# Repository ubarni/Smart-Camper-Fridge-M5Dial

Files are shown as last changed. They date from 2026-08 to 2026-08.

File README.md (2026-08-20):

# Smart Camper Fridge Controller (M5Dial)

An advanced, fully integrated open-source controller for 12V/24V camper refrigerators using SECOP (Danfoss) compressors, powered by an [**M5Stack Dial 1.1**](https://docs.m5stack.com/en/core/M5Dial) running **ESPHome** with **Home Assistant Integration**.

Tested with [**WAECO Coolmatic MDC-090K**](https://github.com/ubarni/Smart-Camper-Fridge-M5Dial/blob/c926922314870ae8d956f22f25ac7502f4ca9708/manual-coolmatic-mdc090k.pdf) and [**SECOP 101N0650 Controller**](https://github.com/ubarni/Smart-Camper-Fridge-M5Dial/blob/c926922314870ae8d956f22f25ac7502f4ca9708/secop_bd35f_bd50f_bd35k_electronic_unit_101n0212_101n0340_101n0650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)

This project provides a modern, touch-enabled smart UI for your fridge, replacing analog thermostats with precise digital temperature management, dynamic compressor speed control, Freezer Guard mode and built-in battery protection.

https://github.com/user-attachments/assets/8034e03e-43d9-4a4a-a77b-4d3339af659d

## Screenshot Home Assistant
[**Smart Fridge (View)**](https://github.com/ubarni/Smart-Camper-Fridge-M5Dial/blob/3c6792e76c0abe57d38a256c658d0e316bda5d45/smart_fridge_view.yaml)
Install via HACS: Template Climate (Integration), Bubble Card (Dashboard), Button Card (Dashboard), Lovelace Mini Graph Card (Dashboard), Card Mod 4 (Dashboard)
Needs: [**climate_template.yaml**](https://github.com/ubarni/Smart-Camper-Fridge-M5Dial/blob/3c6792e76c0abe57d38a256c658d0e316bda5d45/climate_template.yaml)
Bildschirmfoto 2026-08-06 um 20 25 00

## ✨ Features

* **Modern Touch UI & Rotary Encoder:** Intuitive control over temperature and compressor speeds using the M5Dial's rotating bezel and round touch screen.
* **Intelligent Compressor Control:** Variable PWM speed control allows you to run the compressor in `Night` (Quiet/Slow), `Normal`, or `Power` (Fast cooling) modes.
* **Dual-Zone "Freezer Guard" Mode:** Single-compressor RV refrigerators share a single cooling circuit between the main compartment and the freezer. When the Freezer Guard Mode is ON the compressor logic reacts on fridge AND freezer target temperatures. 
* **Locktime:** Prevents the compressor from starting within a preset time. This extends the compressors lifetime.
* **Low Voltage Disconnect (LVD):** Monitors battery voltage and safely shuts down the fridge before your camper's battery is depleted (Configurable via Home Assistant).
* **Failsafe Mechanisms:** Prevents infinite compressor loops if a temperature sensor fails or gets disconnected.
* **SECOP Error Decoding:** Directly reads and decodes the diagnostic pulses from the SECOP controller (e.g., "E3: Motor failure") and displays the exact cause on the screen.
* **Software Power Meter:** Accurately estimates current power consumption (Watts) and integrates it into total Energy (Wh) used.
* **100% Home Assistant Integration:** All presets, parameters, and logs are seamlessly synced with Home Assistant.

## 🛠️ Hardware Requirements

* **M5Stack M5Dial 1.1**
  * 1x [**M5Stack Dial 1.1**](https://shop.m5stack.com/products/m5stack-dial-v1-1) (ESP32-S3 with integrated touch display and rotary encoder) https://shop.m5stack.com/products/m5stack-dial-v1-1
* **DS18B20 Temperature Sensors**
  * 3x DS18B20 temperature sensors supported for Fridge, Freezer, and Compressor
  * 1x 4.7 kΩ Pull-up resistors for the DS18B20 data line
* **36V -> 3.3V analog Voltage Divider** (To safely measure the 12V/24V battery line via the M5Dial's 3.3V ADC)
  * 1x 100 kΩ + 1x 10 kΩ **1% Metal film resistor**
  * 1x 100nF Condensator
* **Optocouplers:**
  * 2x PC817 (For isolating DIAG and PWM signals)
    * **PWM Output:** M5Dial GPIO39 drives the internal LED of the first PC817. The transistor side connects directly to Secop terminals **T** and **C**.
    * **DIAG Input:** Secop terminal **D** drives the second PC817 input. The output transistor pulls **GPIO38** down to GND when active. 
  * 1x 1 kΩ (PWM)
  * 1x 220Ω (DIAG)
* **Connectors:**
  * 2x [**M5Stack Grove cable**](https://shop.m5stack.com/products/4pin-buckled-grove-cable) or JST PH 2.00mm 4 pin female cables
  * 2x [**JST PH 2.00mm 4 pin male PCB connector**] for M5Dial Grove cables
  * 2x [**JST XH 2.54mm 2 pin male PCB connector**] for M5Dial power supply PCB
  * 2x [**JST XH 2.54mm 2 pin female PCB connector**] for M5Dial power supply cable
  * 1x [**JST XH 2.54mm 4 pin male connector**] for SECOP connection PCB
  * 1x [**JST XH 2.54mm 4 pin female PCB connector**] for SECOP connection cable
  * 3x [**JST XH 2.54mm 3 pin male connector**] for DS18B20 connection PCB
  * 3x [**JST XH 2.54mm 3 pin female PCB connector**] for DS18B20 connection cable

---

## 🔌 Wiring (Grove Ports)

The code is pre-configured to utilize the easily accessible Grove ports on the back of the M5Dial:

* **Port A (Red - I2C/GPIO):**
  * `GPIO15` (Yellow Wire): PWM Output to SECOP Controller (Speed limit control).
  * `GPIO13` (White Wire): Input for SECOP Error diagnostic pulses.
* **Port B (Black - I/O/ADC):**
  * `GPIO2` (Yellow Wire): Shared OneWire Data Pin for ALL DS18B20 Temperature Sensors.
  * `GPIO1` (White Wire): ADC Input for Battery Voltage Divider.
---

## Wiring "Diagram"
> ⚠️ **KiCAD and 3D print files will be available after testing**
Smart Camper Fridge M5Stack Dial
Bildschirmfoto 2026-08-19 um 16 03 24
Bildschirmfoto 2026-08-14 um 09 46 03
Bildschirmfoto 2026-08-19 um 16 02 35

**[Click here to see the 3D model of the case](https://github.com/ubarni/Smart-Camper-Fridge-M5Dial/blob/1929dae5fefd54ca2ec57aa82e2640f9eb83e18b/Smart%20Fridge%20Geha%CC%88use.stl)**

---

## Software Installation

1. Copy the contents of `smart-camper-fridge-m5dial.yaml` into your ESPHome environment.
2. The power estimation logic (`fridge_power`) is tuned for a standard SECOP BD35F compressor pulling ~57W at minimum speed and ~72W at full throttle. You can modify these values in the YAML file based on your specific compressor and cooling agent.

3. Create a `secrets.yaml` file in the same directory (or use your existing one) containing your network and access parameters based on the following template:

```yaml
wifi_ssid: "Your_Camper_WIFI"
wifi_password: "Your_Secret_Password"
wifi_backup_ssid: "Your_Backup_Home_WIFI"
wifi_backup_password: "Your_Home_Password"
ap_password: "Fallback_Access_Point_Password"
```

3. Compile and flash the firmware to your M5Dial. If transitioning between compilation environments, performing a **"Clean Build"** prior to flashing is recommended.

---
## 🖱️ User Interface (M5Dial Operation)

The M5Dial offers a highly intuitive, tactile interface using its rotary encoder, touch screen, and integrated physical button. The UI is split into three main modes, color-coded for quick recognition: **Temperature** (Blue), **Compressor Speed** (Orange), and **Brightness** (Yellow).

### 🔄 Rotary Ring (Bezel)
Turning the physical outer ring allows you to manually adjust the target value of the currently active mode:
* **In Temperature Mode:** Adjusts the fridge target temperature (1°C to 20°C).
* **In Compressor Mode:** Adjusts the compressor speed limit (0% to 100%).
* **In Brightness Mode:** Adjusts the screen backlight intensity (10% to 100%).
* **In Freezer Guard Mode:** Adjusts the freezer target temperature (0°C to -20°C).
* *Note: Manually turning the dial will instantly switch the active preset to "Manual" (unless the exact value matches a predefined preset).*

### 👆 Touch Screen Gestures
* **Tap the Center Screen:** Cycles through the three main UI modes (Temperature -> Compressor Speed -> Brightness).
* **Tap the Bottom Area:** Toggles the bottom information bar between two pages:
  * *Page 1:* Sensor Temperatures (Fridge, Freezer, Compressor).
  * *Page 2:* Energy & Connectivity (Power Draw in Watts, Battery Voltage, WiFi Signal Strength).

### 🔘 Physical Button (Below the Screen)
Below the screen of the M5Dial is a physical push button, enabling quick preset changes without looking:
* **Single Click:** Cycles through your configured presets for the currently active mode.
  * *In Temperature Mode:* Cold -> Fresh -> Eco -> Vacation -> ...
  * *In Compressor Mode:* Night -> Normal -> Power -> ...
  * *In Brightness Mode:* 30% -> 70% -> 100% -> ...
  * *In Freezer Guard Mode:* ON -> OFF -> ...
* **Double Click:** Cycles through the three main UI modes (serves as a tactile alternative to tapping the center screen).
* **Long Press (Hold for 1s):** Main Power Switch. Turns the entire fridge system (and the display) ON or OFF (Standby).

---

### 🎨 Dynamic UI Color Concept

The bottom section of the M5Dial display features a color-coded status bar for visual monitoring at a glance:

* **🟦 Fridge (Left Column)**
  * **Icon**: Always **Blue** 🔵
  * 🟢 **Green**: Target temperature reached
  * 🟡 **Yellow**: Above target, but compressor is off (within hysteresis window or locked by delay timer)
  * 🔴 **Red**: Above target **AND** compressor is actively cooling

* **🧊 Freezer (Center Column)**
  * **Icon**: **Cyan** 🧊 when Guard is **ON** | **Gray** ⚪ when Guard is **OFF**
  * **Status (Guard ON)**:
    * 🟢 **Green**: Freezer target temperature reached
    * 🟡 **Yellow**: Above target, compressor waiting
    * 🔴 **Red**: Above target **AND** compressor actively cooling
  * **Status (Guard OFF)**:
    * ⚪ **White**: Neutral display

* **⚙️ Compressor (Right Column)**
  * **Icon & Text**: 
    * 🟠 **Orange**: Compressor is running
    * ⚪ **Gray**: Compressor is in standby
---

## UI Calibration Guide

Once the controller boots up and integrates into Home Assistant, you will find four unique calibration entities under your device settings. This allows you to configure your controller perfectly on any custom PCB design without changing the code:

## ⚙️ Calibration & Configuration

The system exposes a comprehensive set of configuration entities directly to Home Assistant. This allows you to fine-tune the fridge's behavior on the fly without having to recompile or flash the ESP32.

### General Settings
* **Low Voltage Cutoff (LVD):** Sets the minimum battery voltage (e.g., `11.5V`) before the fridge automatically shuts down to protect your camper's battery.
* **Startup Lock Duration:** Defines the minimum wait time (in seconds, default `30s`) between compressor cycles to equalize system pressure and protect the compressor motor.
* **Hysteresis:** The temperature tolerance (e.g., `1.5°C`). If target is 5°C, it cools until 5°C and waits until it reaches 6.5°C before starting again.

### Temperature Presets
You can define the exact target temperatures for the UI presets:
* **Temp Preset Cold:** (Default `2°C`)
* **Temp Preset Fresh:** (Default `4°C`)
* **Temp Preset Eco:** (Default `6°C`)
* **Temp Preset Vacation:** (Default `10°C`)

### Compressor Speed Presets
You can configure the exact PWM output limits (0-100%) for the different compressor modes:
* **Compressor Preset Night:** Ultra-quiet, slow running (Default `20%`)
* **Compressor Preset Normal:** Standard operation (Default `50%`)
* **Compressor Preset Power:** Fast cooling (Default `80%`)

### Voltage Calibration
To calibrate the voltage you need two measurements:
* **1. Voltage when battery is full:** Use the Voltage-Multiplier slider until the shown voltage corresponds to the measured voltage
* **2. Voltage when battery is empty:** Use the Voltage-Offset slider until the shown voltage corresponds to the measured voltage

### Hardware Calibration
* **Voltage-Multiplier:** Adjusts the ADC reading to match your physical voltage divider circuit. Measure your battery with a multimeter and adjust this multiplier until the M5Dial matches the real voltage.
* **Sensor Assignment:** The system uses 3 physical DS18B20 OneWire sensors. Since OneWire addresses can change, you can dynamically assign which index (`Index 0`, `Index 1`, `Index 2`) corresponds to the `Fridge`, `Freezer`, or `Compressor` directly via Home Assistant dropdown menus!

### Power Estimation Tuning
Because the system (no more GPIOs) lacks a physical shunt resistor, power consumption is estimated based on the compressor speed. 
If you want to calibrate this to your specific compressor, measure the consumption at lowest (0%) and highest (100%) speed using a SmartShunt. Then, update the lambda in the `fridge_power` sensor within the YAML file:
```yaml
// Example: ~57W at minimum speed, ~72W at full throttle (15W span)
return 57.0f + ((speed / 100.0f) * 15.0f);
```
Bildschirmfoto 2026-07-29 um 21 32 17
Bildschirmfoto 2026-07-29 um 21 32 30
Bildschirmfoto 2026-07-29 um 21 32 51

## License & Contributing

Free to fork this project, report issues, or submit pull requests. Let's make mobile off-grid living more efficient together! 
Developed by [ubarni](https://github.com/ubarni). Distributed under the MIT License.

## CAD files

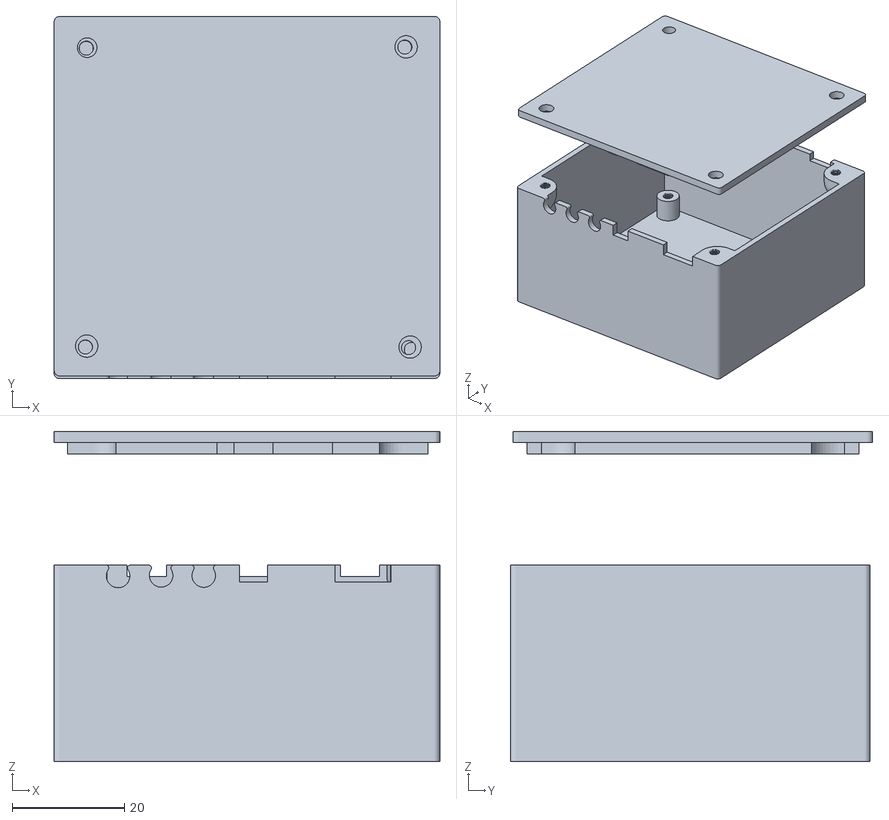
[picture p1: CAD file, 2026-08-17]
Smart Fridge Gehäuse.stl
68.7 x 64.5 x 58.8

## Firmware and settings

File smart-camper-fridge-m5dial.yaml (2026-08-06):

substitutions:
  name: "smart-camper-fridge-m5dial"
  friendly_name: "Smart Camper Fridge M5Dial"
  
  # External pins via M5Dial Grove connectors
  pwm_pin:        "GPIO15" # Port A Yellow (PWM output to SECOP controller)
  diag_pin:       "GPIO13" # Port A White  (Input for SECOP diagnostic pulses)

  dallas_bus_pin: "GPIO2"  # Port B Yellow (Shared pin for ALL 3 OneWire temp sensors)
  voltage_pin:    "GPIO1"  # Port B White  (Input for battery voltage divider)
  
esphome:
  name: ${name}
  friendly_name: ${friendly_name}
  on_boot:
    priority: 800
    then:
      # 1. Initialize error text sensor to OK via Lambda
      - lambda: |-
          id(secop_error_text).publish_state("OK");
      # 2. Set backlight initially to 70% via number component
      - number.set:
          id: display_brightness_pct
          value: 70

esp32:
  variant: esp32s3
  framework:
    type: arduino

logger:
  level: DEBUG
  logs:
    sensor: INFO
    adc: INFO

api:
  encryption:
    key: "UpqtwOF9dFA0zdkV585rFijX4IySnybn2vuiYRxFG/g="

ota:
  - platform: esphome
    password: "33c564707f7fd52c1bcca740107f8da4"
    
wifi:
  networks:
    - ssid: !secret wifi_ssid_ssid
      password: !secret wifi_ssid_password
      priority: 1
    - ssid: !secret wifi_backup_ssid_ssid
      password: !secret wifi_backup_ssid_password
      priority: 10
  fast_connect: false
  power_save_mode: none
  ap:
    ssid: "Camper Fridge"
    password: !secret ap_password

captive_portal:
  
web_server:
  port: 80
  version: 3
  local: true

globals:
  - id: last_compressor_stop
    type: uint32_t
    initial_value: '0'
  - id: is_updating
    type: bool
    initial_value: 'false'
  - id: in_soft_start
    type: bool
    initial_value: 'false'
  - id: error_pulse_count
    type: int
    initial_value: '0'
  - id: ui_mode
    type: int
    initial_value: '0'     # 0 = Temp (Blue), 1 = Speed (Orange), 2 = Brightness (Yellow)
  - id: lower_display_page
    type: int
    initial_value: '0'     # 0 = All Temperatures, 1 = Power & Battery
  - id: soft_start_start_time
    type: uint32_t
    initial_value: '0'

# Internal I2C bus for the M5Dial touchscreen board
i2c:
  - id: bus_internal
    sda: GPIO11
    scl: GPIO12
    frequency: 400kHz   
    scan: true

# Touchscreen driver
touchscreen:
  - platform: ft5x06
    address: 0x38
    id: dial_touch
    i2c_id: bus_internal
    interrupt_pin: GPIO14

# Internal SPI bus configuration for the M5Dial display
spi:
  id: spi_bus
  mosi_pin: GPIO5
  clk_pin: GPIO6
    
output:
  - platform: ledc
    pin: GPIO9
    id: backlight_output
    
  - platform: ledc
    pin: ${pwm_pin}
    id: secop_pwm_output
    frequency: 5000Hz

light:
  - platform: monochromatic
    name: "Display Backlight"
    output: backlight_output
    id: display_backlight
    restore_mode: RESTORE_DEFAULT_OFF

# Central OneWire bus on a single pin
one_wire:
  - platform: gpio
    pin: ${dallas_bus_pin}
    id: dallas_bus

sensor:
  # --- HARDWARE SENSORS (Reads values sequentially from the bus) ---
  - platform: dallas_temp
    one_wire_id: dallas_bus
    index: 0
    id: raw_sensor_0
    name: "Physical Sensor Index 0"
    update_interval: 10s
    entity_category: "diagnostic"

  - platform: dallas_temp
    one_wire_id: dallas_bus
    index: 1
    id: raw_sensor_1
    name: "Physical Sensor Index 1"
    update_interval: 10s
    entity_category: "diagnostic"

  - platform: dallas_temp
    one_wire_id: dallas_bus
    index: 2
    id: raw_sensor_2
    name: "Physical Sensor Index 2"
    update_interval: 10s
    entity_category: "diagnostic"

  # --- VIRTUAL SENSORS (Future-proof assignment without deprecation warnings) ---
  - platform: template
    name: "Temp Fridge"
    id: fridge_temp
    unit_of_measurement: "°C"
    update_interval: 10s
    filters:
      - sliding_window_moving_average:
          window_size: 6 
          send_every: 1 
    lambda: |-
      std::string choice = id(select_fridge_sensor).current_option(); // <-- Update for ESPHome 2026.7+
      if (choice == "Index 0") return id(raw_sensor_0).state;
      if (choice == "Index 1") return id(raw_sensor_1).state;
      return id(raw_sensor_2).state;

  - platform: template
    name: "Temp Freezer"
    id: freezer_temp
    unit_of_measurement: "°C"
    update_interval: 10s
    lambda: |-
      std::string choice = id(select_freezer_sensor).current_option();
      if (choice == "Index 0") return id(raw_sensor_0).state;
      if (choice == "Index 1") return id(raw_sensor_1).state;
      return id(raw_sensor_2).state;

  - platform: template
    name: "Temp Compressor"
    id: compressor_temp
    unit_of_measurement: "°C"
    update_interval: 10s
    lambda: |-
      std::string choice = id(select_compressor_sensor).current_option();
      if (choice == "Index 0") return id(raw_sensor_0).state;
      if (choice == "Index 1") return id(raw_sensor_1).state;
      return id(raw_sensor_2).state;
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

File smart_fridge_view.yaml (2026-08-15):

# Add a view, 3 dots menu -> Edit in Yaml, paste this code
# Install via HACS: Template Climate (Integration), Bubble Card (Dashboard), Button Card (Dashboard), Lovelace Mini Graph Card (Dashboard), Card Mod 4 (Dashboard)
# Needs: climate_template.yaml (i.e. as package),
type: sections
max_columns: 1
title: Camper Fridge
path: camper-fridge
icon: mdi:fridge
sections:
  - type: grid
    cards:
      - type: heading
        icon: mdi:fridge
        heading: Fridge Control
        heading_style: subtitle
        badges:
          - type: entity
            show_state: true
            show_icon: true
            entity: sensor.smart_fridge_fridge_voltage
            tap_action:
              action: more-info
          - type: entity
            show_state: true
            show_icon: true
            entity: sensor.smart_fridge_fridge_power
            tap_action:
              action: more-info
          - type: entity
            show_state: true
            show_icon: true
            entity: sensor.smart_fridge_fridge_error
            visibility:
              - condition: state
                state_not: OK
            tap_action:
              action: more-info
            color: red
      - type: custom:mushroom-entity-card
        entity: sensor.smart_fridge_fridge_error
        layout: horizontal
        icon_color: red
        primary_info: state
        secondary_info: name
        name: FRIDGE ERROR
        card_mod:
          style: |
            mushroom-state-info {
              --card-primary-font-weight: 700;
              --card-secondary-font-weight: 700;
              --primary-color: red;
            }
        visibility:
          - condition: state
            state_not: OK
      - type: custom:mushroom-entity-card
        entity: sensor.smart_fridge_lock_remain
        layout: horizontal
        icon_color: red
        primary_info: name
        secondary_info: state
        name: Lock Remain
        visibility:
          - condition: numeric_state
            above: 0
        card_mod:
          style: |
            mushroom-state-info {
              --card-primary-font-weight: 700;
              --card-secondary-font-weight: 700;
              --primary-color: red;
            }
      - type: custom:mushroom-entity-card
        entity: sensor.smart_fridge_fridge_state
        layout: default
        icon_color: primary
        primary_info: state
        secondary_info: last-changed
        grid_options:
          columns: full
          rows: 1
        fill_container: false
        tap_action:
          action: more-info
      - type: custom:mushroom-entity-card
        entity: sensor.smart_fridge_last_setting
        layout: horizontal
        icon_color: primary
        primary_info: state
        secondary_info: last-changed
        grid_options:
          columns: 12
          rows: 1
      - type: entities
        entities:
          - entity: sensor.smart_fridge_temp_fridge
            name: Fridge
            icon: mdi:thermometer
            card_mod:
              style: |
                hui-generic-entity-row {
                  {% set state = states(config.entity) | float(default=0) %}
                  {% set state_color = '77, 126, 189' %}
                  {% set level = states("sensor.smart_fridge_temp_fridge") | int %}
                  {% set min_state = 5 %}
                  {% set max_state = 20 %}
                  {% set critical_state = 15 %}
                  {% set critical_color = '135, 18, 18' %}
                  {% set percent = ((state - min_state) / (max_state - min_state) * 100) | round(1) %}
                  {% set bar_color = state_color if state < critical_state else critical_color %}
                  background: linear-gradient(
                    90deg,
                    rgba({{ bar_color }}, 0.9) 0%,
                    rgba({{ bar_color }}, 0.9) {{ percent }}%,
                    rgba({{ bar_color }}, 0.5) {{ percent }}%,
                    rgba({{ bar_color }}, 0.15) 100%
                  );
                }
          - entity: sensor.smart_fridge_temp_freezer
            name: Freezer
            icon: mdi:snowflake
            card_mod:
              style: |
                hui-generic-entity-row {
                  {% set state = states(config.entity) | float(default=0) %}
                  {% set state_color = '5, 60, 240' %}
                  {% set level = states("sensor.smart_fridge_temp_freezer") | int %}
                  {% set min_state = -20 %}
                  {% set max_state = 0 %}
                  {% set critical_state = -2 %}
                  {% set critical_color = '135, 18, 18' %}
                  {% set percent = ((state - min_state) / (max_state - min_state) * 100) | round(1) %}
                  {% set bar_color = state_color if state < critical_state else critical_color %}
                  background: linear-gradient(
                    90deg,
                    rgba({{ bar_color }}, 0.9) 0%,
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

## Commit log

2026-08-06 Update smart-camper-fridge-m5dial.yaml
    Added Freezer Guard Mode and coloring of the temperatures and icons in the status bar.
2026-08-10 Update README.md
    Added Voltage Calibration
2026-08-10 Update smart-fridge.yaml
    Changed Voltage Calibration.
2026-08-10 Update smart-fridge.yaml
    Hide compressor_state switch and add compressor_running binary_sensor instead. (Safety to not switch the compressor off directly)
2026-08-14 Update README.md
    Added KiCAD preview
2026-08-15 Update smart-fridge.yaml
    Some UI improvements.
    Voltage measurement updated with 100k resistor to fit 24V measurement.
2026-08-17 Update README.md
    Added 3D model of the case
